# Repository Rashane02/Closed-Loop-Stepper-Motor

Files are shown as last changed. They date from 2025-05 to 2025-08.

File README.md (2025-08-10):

# 🚀 Closed-Loop Stepper Motor Control System  

A **high-performance closed-loop stepper motor system** powered by **Field-Oriented Control (FOC)** and **Space Vector Modulation (SVM)**, delivering **precise**, **smooth**, and **efficient motion control**.  

Real-time **encoder feedback** ensures **zero step loss**, even under heavy dynamic loads – making this system ideal for **robotics**, **CNC machines**, and **advanced automation** applications.  

---

## ✨ Features  

✅ **Closed-Loop Feedback** – Quadrature encoder eliminates step loss by constantly correcting position in real time.  
✅ **FOC (Field-Oriented Control)** – Decoupled torque & flux control for buttery-smooth motion.  
✅ **SVM (Space Vector Modulation)** – Generates efficient, optimized PWM waveforms.  
✅ **Dead-Time Insertion** – Prevents MOSFET shoot-through for safe, reliable switching.  
✅ **Multi-Mode Control**:  
   - 🎯 **Torque Mode** – Direct torque regulation via Q-axis current.  
   - ⚡ **Speed Mode** – Outer PI speed loop for consistent velocity.  
   - 📍 **Position Mode** – Expandable to precision positioning applications.  
✅ **Load Disturbance Compensation** – Maintains performance under sudden mechanical shocks.  

---

## 🛠 Hardware Setup  

- **Stepper Motor**: NEMA17 w/ integrated magnetic encoder  
- **Encoder**: Quadrature rotary encoder  
- **MCU**: TI **TMS320F28069M** (C2000 series – optimized for motor control)  
- **Driver**: Toshiba **TB67H400A** H-bridge driver  
- **Power Supply**: 24V SMPS  
- **Dev Board**: TI **LAUNCHXL-F28069M** + XDS110 Debugger  

---

## 🧠 Software Architecture  

- 🌀 **FOC Engine** – Implements **Clarke & Park transforms** for current regulation.  
- ⚙️ **Current Control Loop** – Inner PI loop for **Id/Iq** current control.  
- 🚀 **Speed Control Loop** – Outer PI loop regulates speed based on encoder feedback.  
- 🔺 **SVM** – Generates smooth PWM signals for precise voltage vector control.  
- ⏱ **Dead-Time Management** – Ensures MOSFET safety during commutation.  
- 🎯 **Encoder Interface (eQEP)** – Real-time speed & position tracking.  
- 📊 **Current Sensing & Calibration** – Phase current monitoring with ADC correction.  
- ⚡ **Interrupt-Driven Control** – High-speed ISR-based execution for ultra-low latency.  
- 🎛 **PWM Generation** – Configured for **10 kHz switching** using TI’s ePWM modules.  
- 🔧 **Utility Layer** – IQmath-based helpers for sign detection, clamping & timing.  

---

## 🎮 Control Modes  

### 🔴 Torque Mode  
Controls motor torque **directly** by regulating Q-axis current. Perfect for force-sensitive applications like **robot arms** or **actuators**.  

### 🟠 Speed Mode  
A **cascaded PI loop** sets torque (Iq) based on speed error – ensuring **steady, ripple-free velocity**.  

### 🟢 Position Mode *(Scalable)*  
An **outer position loop** feeds commands to the speed loop – enabling high-precision motion like **CNC**, **pick-and-place machines**, or **3D printers**.  

---

## 🔬 Prototype  

🖼 *Compact design built for performance testing*  

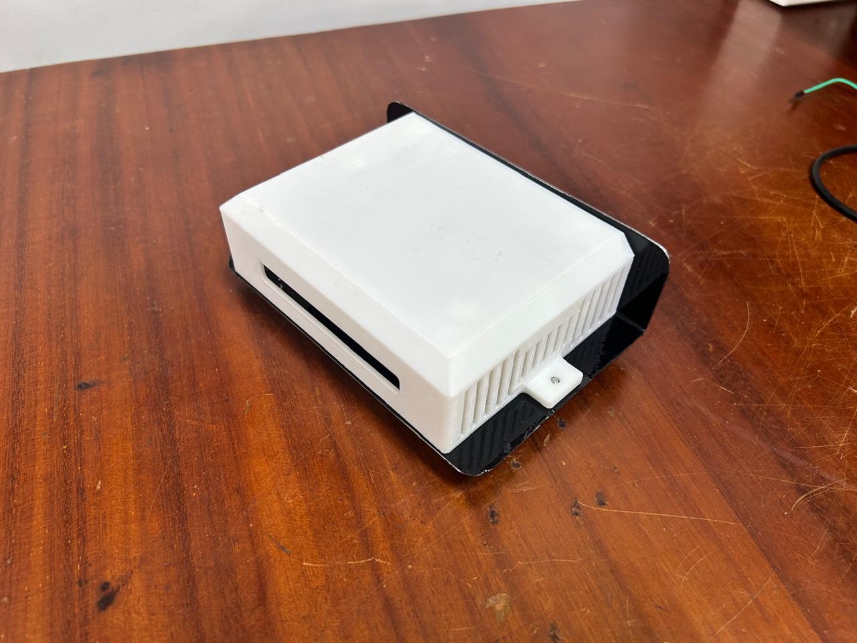
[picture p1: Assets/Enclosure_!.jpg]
  
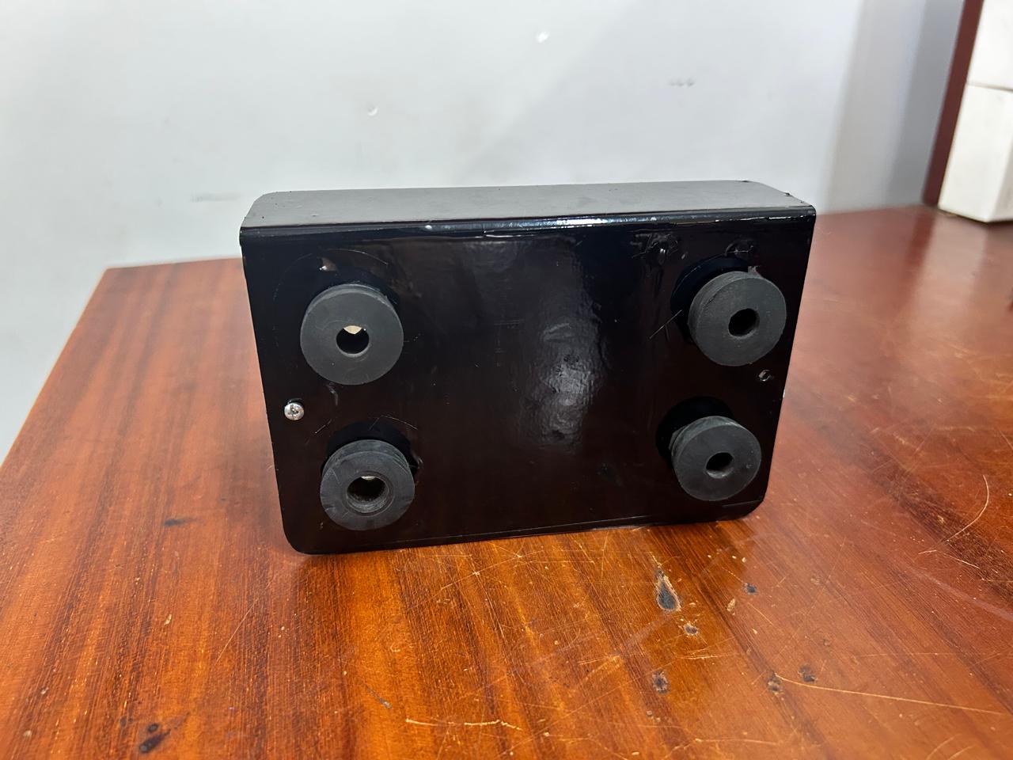
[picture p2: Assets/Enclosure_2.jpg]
  

---

## ⚡ PCB Design  

A **4-layer PCB** designed for **thermal efficiency**, **signal integrity**, and **high-current handling**.  

- ✅ Optimized power & ground planes for **low-noise FOC**.  
- ✅ Carefully routed encoder & current sense lines for **accurate feedback**.  
- ✅ Built-in dead-time safe switching logic.  

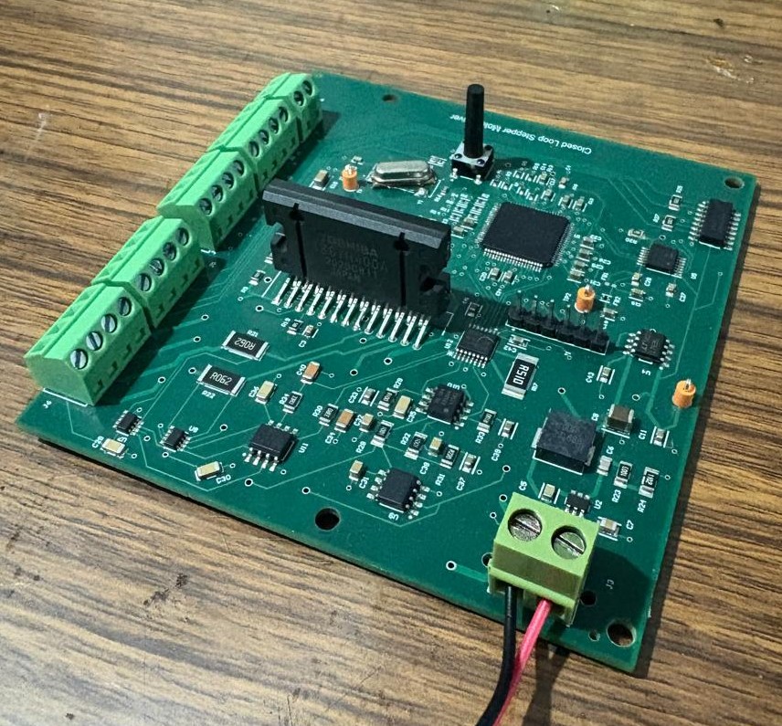
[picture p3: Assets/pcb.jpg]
  
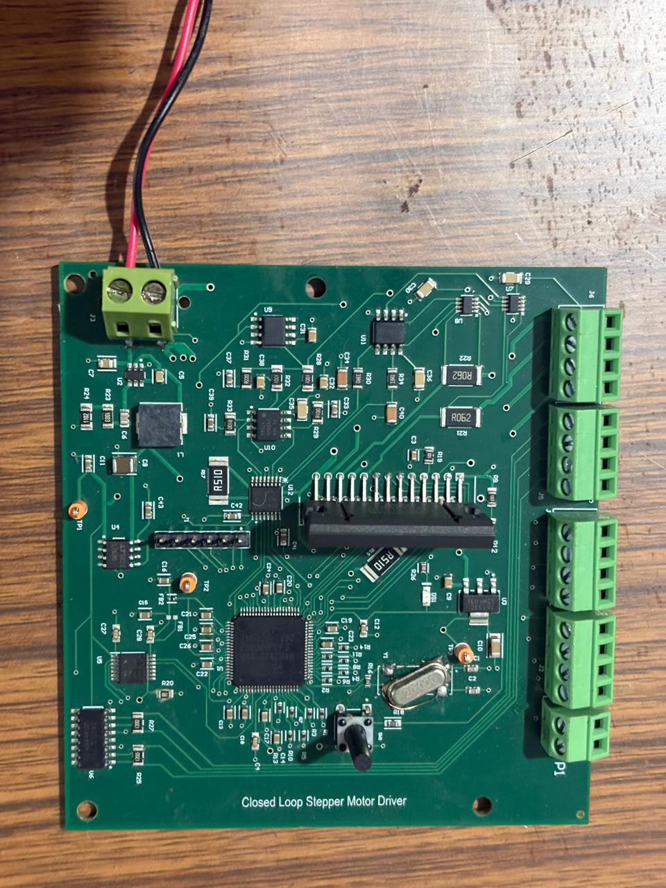
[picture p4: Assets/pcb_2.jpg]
  

---

## 📚 References  

📘 [TI – Field Oriented Control Overview](https://www.ti.com/video/6296584406001)  
📘 [TI – C2000 Motor Control User Guide](https://www.tij.co.jp/jp/lit/ug/spru556/spru556.pdf)  
📘 [TI – InstaSPIN FOC Documentation](https://www.ti.com/lit/pdf/sprui11)

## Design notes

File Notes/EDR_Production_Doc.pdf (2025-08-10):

## University of Moratuwa

## Faculty of Engineering

## Department of Electronic & Telecommunication Engineering

21st of May, 2025

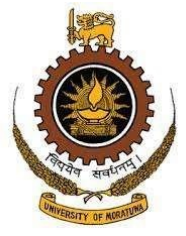
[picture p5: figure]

EN2160: Electronic Design Realization

## Production Documents for Closed Loop Stepper Motor Project

Group Members:

220169V | Fernando S.R.N.
220276V | Jayathissa M.P.N.V
220134K | Dissanayaka D.M.A.D.
220353F | Lakshan K.P.
220355M | Lakshan R.G.R.
220386H | Manujaya U.G.P.
220472T | Perera P.L.P.
220683P | Weerakoon W.M.B.H

# Contents

## 1 Introduction

This production report details the development of a closed-loop stepper motor control system designed for high-performance and cost-effective motion control applications. This project focuses on building a dedicated motor driver from scratch using a Texas Instruments C2000 series microcontroller. The system implements Field-Oriented Control (FOC) and real-time feedback

to achieve precise position and speed control, along with fault detection. The report outlines the complete production process, including hardware and software design, integration, testing and evaluation procedures, and cost estimation, providing a comprehensive plan for future scalability and manufacturing.

## 2 Block Diagram

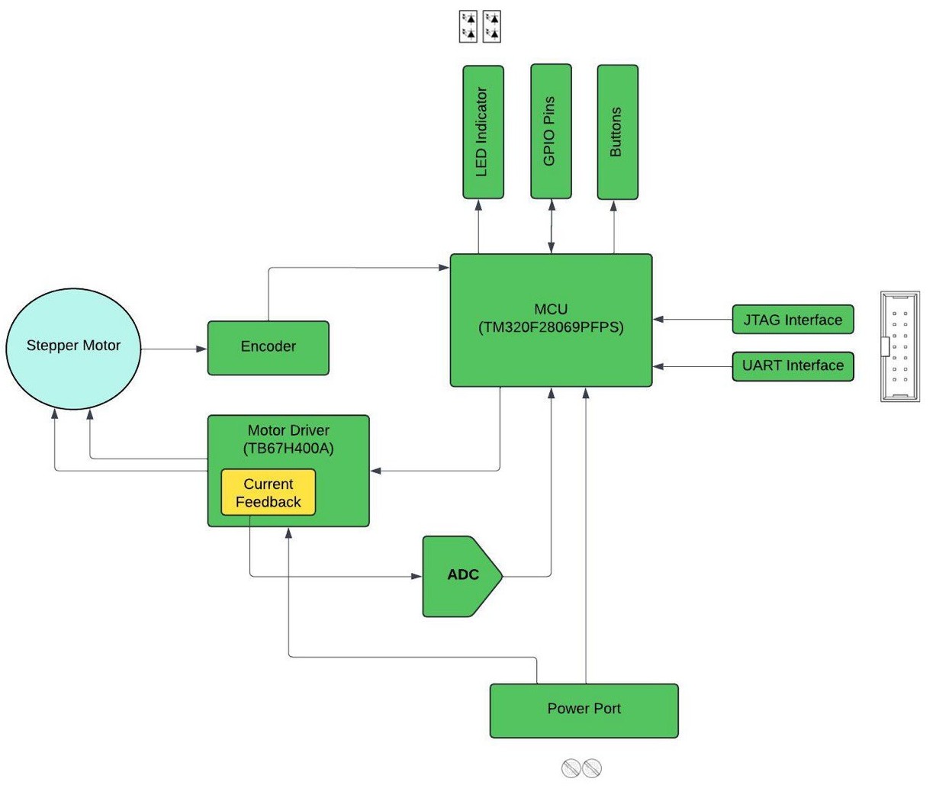
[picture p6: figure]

Figure 1: Block Diagram of the System

## 3 Hardware Design

### 3.1 Schematic

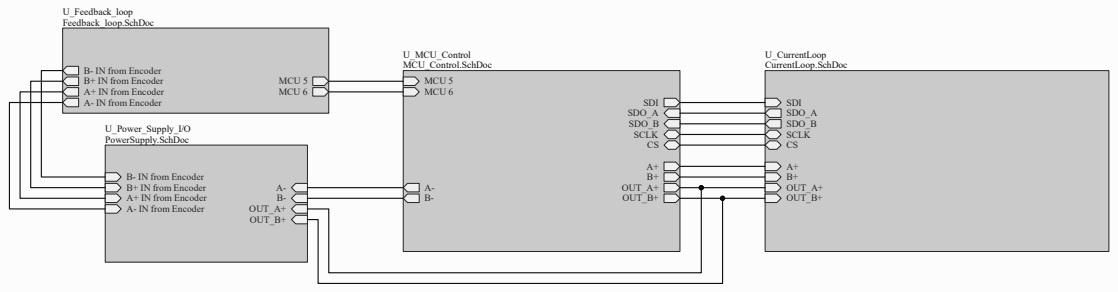
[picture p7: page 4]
Size; Number; Revision; Date:; Sheet of; File:; C:\Users\..\top_level.SchDoc; Drawn By:; 01 Version 5; Jayathissa M.P.N.V.; MCU 5 MCU 6; OUT_A+; OUT_B+; SDO_B; SDO_A; SDI; SCLK CS; U_MCU_Control MCU_Control.SchDoc; U_Feedback_loop Feedback_loop.SchDoc; SCLK; SDI SDO_A SDO_B; U_CurrentLoop CurrentLoop.SchDoc; U_Power_Supply_I/O PowerSupply.SchDoc

B- IN from Encoder
B+ IN from Encoder
A+ IN from Encoder
A- IN from Encoder

Title
Closed Loop Stepper- Top Level

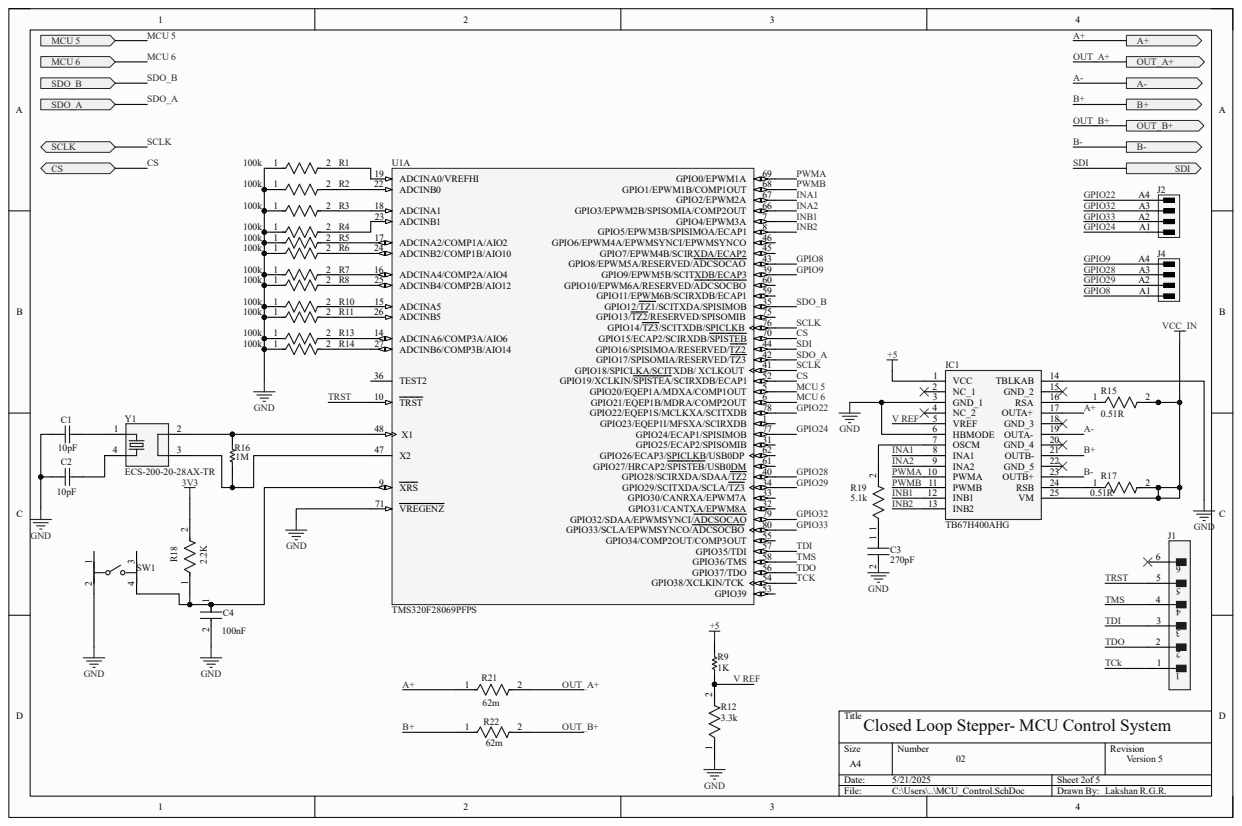
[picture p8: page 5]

Title
Closed Loop Stepper- MCU Control System

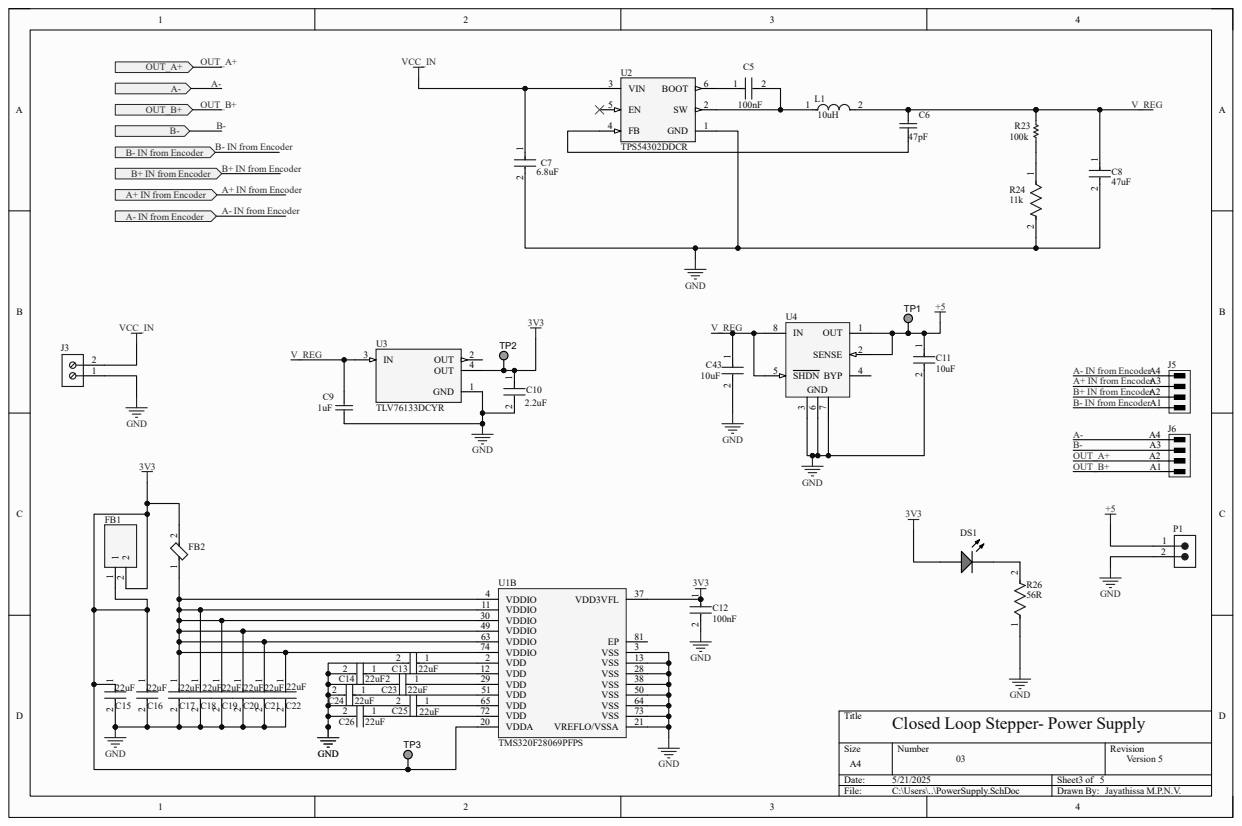
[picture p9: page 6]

Title
Closed Loop Stepper- Power Supply

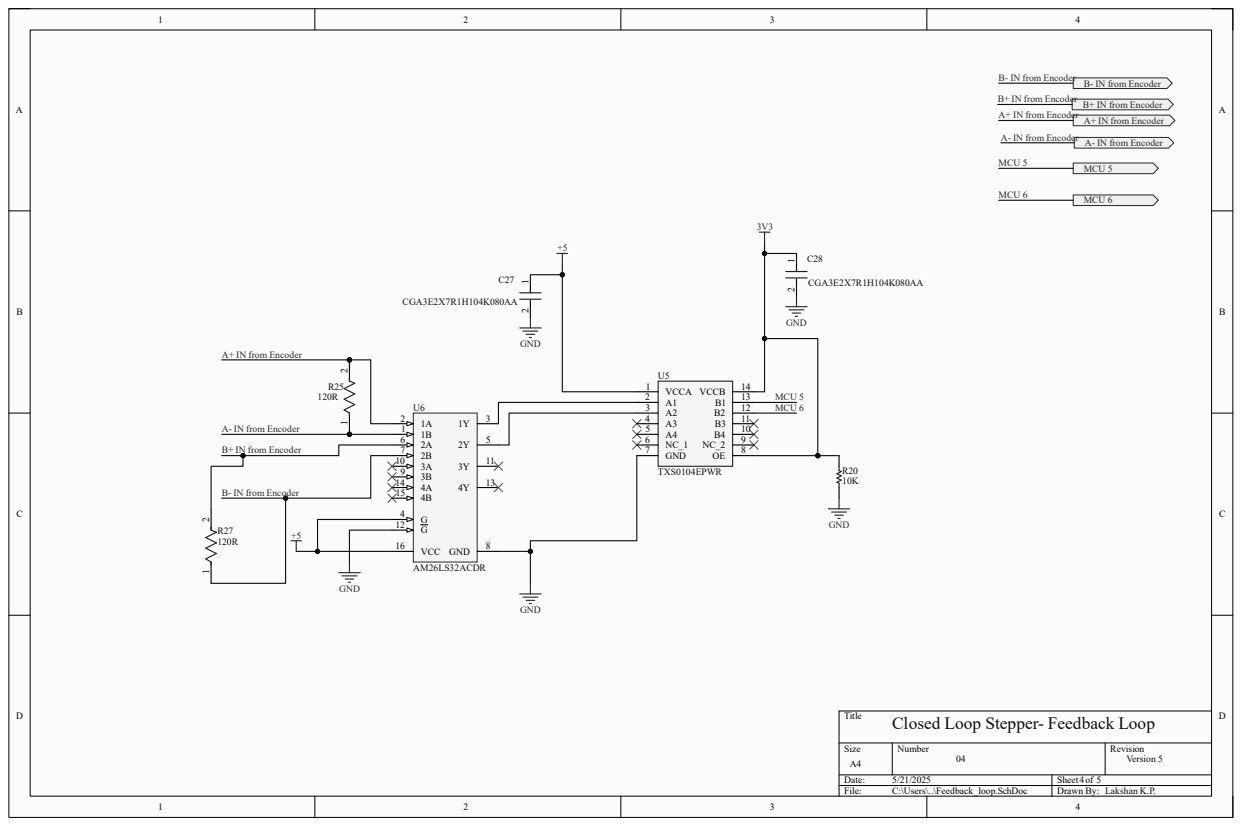
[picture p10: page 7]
Size; Number; Revision; Date:; Sheet of; File:; C:\Users\..\Feedback_loop.SchDoc; Drawn By:; 04 Version 5; GND; VCC 16; AM26LS32ACDR; CGA3E2X7R1H104K080AA; VCCA 1 A1 2 A2 3 A3 4 A4 5 NC_1 6 GND 7; VCCB; TXS0104EPWR; MCU 5 MCU 6; MCU 5; MCU 6; Lakshan K.P.

B- IN from Encoder

B+ IN from Encoder
A+ IN from Encoder

A- IN from Encoder

Title
Closed Loop Stepper- Feedback Loop

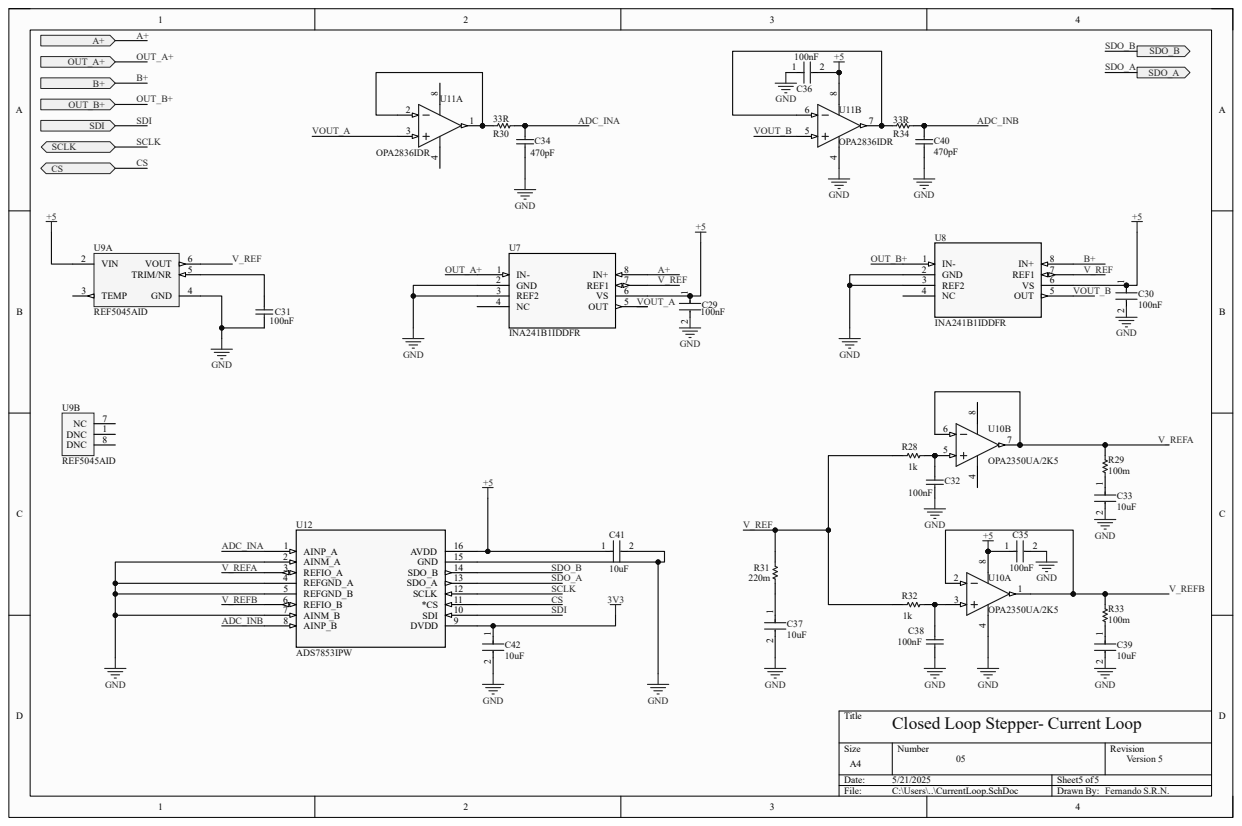
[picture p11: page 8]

GND
Closed Loop Stepper- Current Loop

### 3.2 Components

Designator | Description | Manufacturer / Part Number
C1, C2 | 10pF, ±5%, 50V, 0603, NP0 | Yageo / CC0603JRNPO9BN100
C3 | 270pF, 50V, C0G/NP0, 0603 | KEMET / C0603C271J5GACTU
C4, C12, C27, C28 | 100nF, 50V, X7R, 0603, Automotive | TDK / CGA3E2X7R1H104K080AA
C5 | 0.1uF, 50V, X7R, 0805 | KEMET / C0805C104M5RACTM
C6 | 470pF, 50V, NP0, 0805 | Murata / GQM2195C1H470JB01D
C7 | 6.8uF, 35V, X5R, 0805 | TDK / C2012X5R1V685K125AC
C8 | 47uF, 16V, X5R, 1210 | Murata / GRM32ER61C476KE15L
C9, C31, C32, C38 | 0.1uF, 50V, X7R, 0805 | Kyocera AVX / C0805C105K4PACTU
C10 | 2.2uF, 100V, X7S, 1206 | TDK / C3216X7S2A225K160AB
C11, C33, C37, C39, C41–C43 | 10uF, 6.3V, X5R, 0603 | Murata / GRM188R60J106ME47D
C13–C26 | 22uF, 10V, X5R, 0603 | Murata / GRM188R61A226ME15D
C29, C30, C35, C36 | 0.1uF, 100V, X7R, 1206 | KEMET / C1206C104K1RACTU
C34, C40 | 470pF, 500V, 1206 | Kyocera AVX / 12067A471JAT2A
DS1 | Green Chip LED, 2.2V | Broadcom Avago / HSMG-C170
FB2 | 60Ω, 100MHz, 0402F erriteBead | Murata / BLM15PD600SN1D
J1 | CONN HEADER VERT 6POS 2.54MM | Molex / 22-28-4060
J2, J4–J6 | Terminal Block, 3.50mm | Weidmuller / 1604490000
J3 | 2-pin Terminal Block | Wurth Electronics / 691709710302
L1 | Inductor 10uH, 4.5A | Vishay Dale / IHLP2525EZER100M01

Designator | Description | Manufacturer / Part Number
P1 | 2-pin Header | Wurth Electronics / 691321100002
R1–R14 | 100kΩ, 1/16W, 0402 | Yageo / RC0402JR-07100KL
R9 | 1kΩ, 1%, 0805 | Yageo / RC0805FR-071KL
R12 | 3.3kΩ, 1%, 0805 | Vishay / CRCW08053K30FKEA
R15, R17 | 0.51Ω, 1%, 2W, 2512 | Stackpole / CSRN2512FTR510
R16 | 1MΩ, 5%, 0603 | Panasonic / ERJ-3GEYJ105V
R18 | 2.2kΩ, 1%, 0603 | Vishay / CRCW06032K20FKEAHP
R19 | 5.1kΩ, 1%, 0805 | Vishay / CRCW08055K10FKEA
R20 | 10kΩ, 1%, 0805 | Yageo / RC0805FR-0710KL
R21, R22 | 0.062Ω, 1%, 1W, 2512 | Rohm / MCR100JZHFSR062
R23 | 100kΩ, 1%, 1206 | Bourns / CR1206-FX-1003ELF
R24 | 11kΩ, 1%, 1206 | Vishay / CRCW120611K0FKEA
R25, R27 | 120Ω, 1%, 1206 | Vishay / CRCW1206120RFKEA
R26 | 56Ω, 5%, 0603 | Vishay Dale / CRCW060356R0JNEA
R28, R32 | 1kΩ, 1%, 1206 | Yageo / RC1206FR-071KL
R29, R33 | 100mΩ, 1%, 1206 | Vishay Dale / WSL1206R1000FEA
R30, R34 | 33Ω, 1%, 1206 | Panasonic / ERJ-8ENF33R0V
R31 | 0.22Ω, 1%, 1206 | Panasonic / ERJ-8RQFR22V
SW1 | Tactile Switch SPST-NO, 0.05A 24V | TE Connectivity / 3-1825910-1
TP1–TP3 | Test Point, Orange, THD | Keystone / 5003
U1 | Piccolo Microcontroller, 80-pin HTQFP | TI / TMS320F28069PFPS
U2 | Buck Regulator 3A, TSOT-23-6 | TI / TPS54302DDCR

Designator | Description | Manufacturer / Part Number
U3 | 1A Linear Regulator, 16V, SOT-223 | TI / TLV76133DCYR
U4 | 500mA LDO Regulator, SOIC-8 | Analog Devices / LT1763CS8-5TRPBF
U6 | Line Receiver, 16-Pin SOIC | TI / AM26LS32ACDR
U9 | Precision Voltage Ref, 8-Pin SOIC | TI / REF5045AID
U10 | Rail-to-Rail Op Amp, SOIC-8 | TI / OPA2350UA/2K5
U11 | Dual Op Amp, SOIC-8 | TI / OPA2836IDR

Table 1: Full Bill of Materials (BOM)

Component Designator | Price (USD)
C1, C2 | 0.20
C3 | 0.10
C4, C12, C27, C28 | 0.38
C5 | 0.10
C6 | 0.10
C7 | 0.60
C8 | 1.23
C9, C31, C32, C38 | 0.14
C10 | 0.53
C11, C33, C37, C39, C41–C43 | 0.46
C13–C26 | 0.56
C29, C30, C35, C36 | 0.64
C34, C40 | 0.76
DS1 | 0.28
FB2 | 0.10
J1 | 0.12
J2, J4–J6 | 8.32
J3 | 2.68
L1 | 1.72
P1 | 0.40
R1–R14 | 0.07
R9 | 0.10
R12 | 0.03
R15, R17 | 0.74
R16 | 0.10
R18 | 0.02
R19 | 0.02
R20 | 0.10

Component Designator | Price (USD)
R21, R22 | 0.02
R23 | 0.01
R24 | 0.02
R25, R27 | 0.03
R26 | 0.03
R28, R32 | 0.20
R29, R33 | 0.46
R30, R34 | 0.32
R31 | 0.22
SW1 | 0.08
TP1–TP3 | 0.84
U1 | 18.05
U2 | 0.80
U3 | 0.41
U4 | 6.71
U6 | 0.55
U9 | 4.00
U10 | 4.54
U11 | 3.82
Total Component Cost | 58.58

Table 2: Component Prices and Total Cost

### 3.3 PCB Layer Stackup

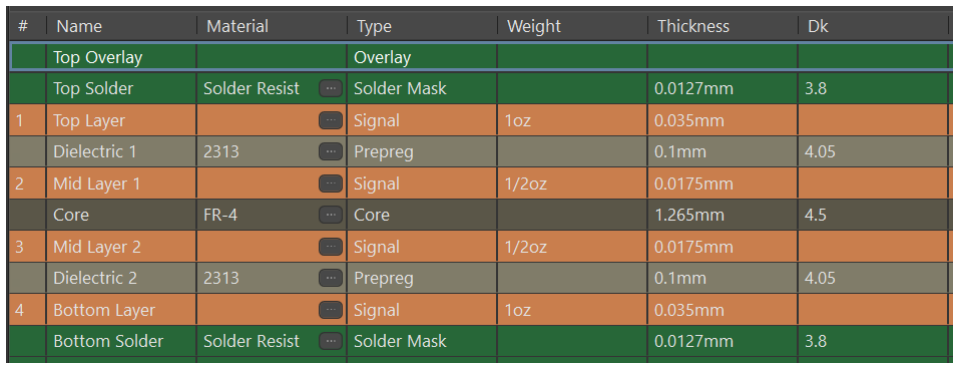
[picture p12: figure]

Figure 2: PCB Layer Stackup

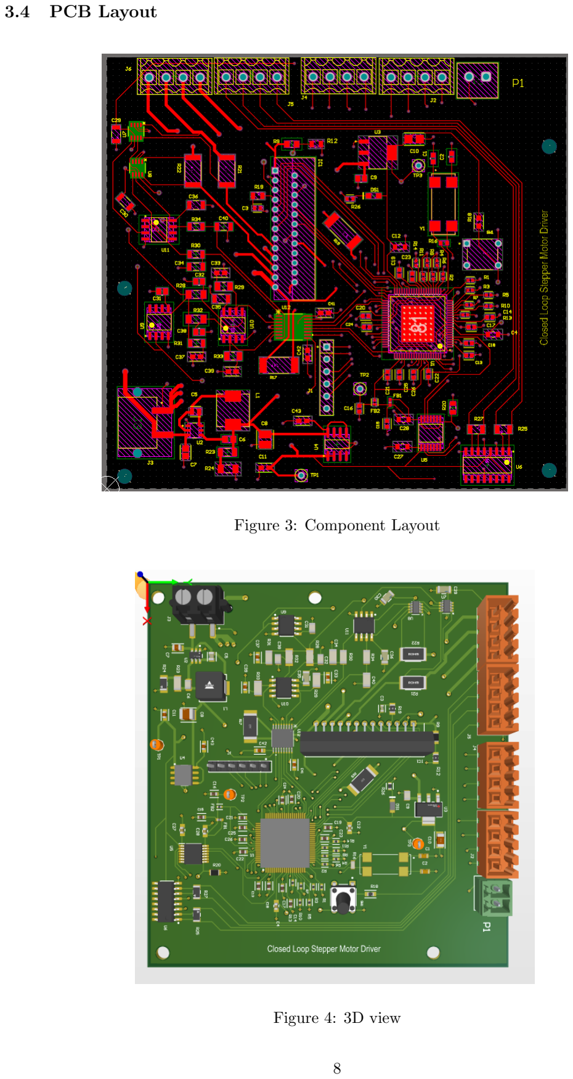
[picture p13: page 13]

### 3.4 PCB Layout

Figure 3: Component Layout

Figure 4: 3D view

PCB design documents can be accessed from this link: https://github.com/Rashane02/Closed-

Loop-Stepper-Motor (https://github.com/Rashane02/Closed-Loop-Stepper-Motor)

### 3.5 Enclosure Design

External View

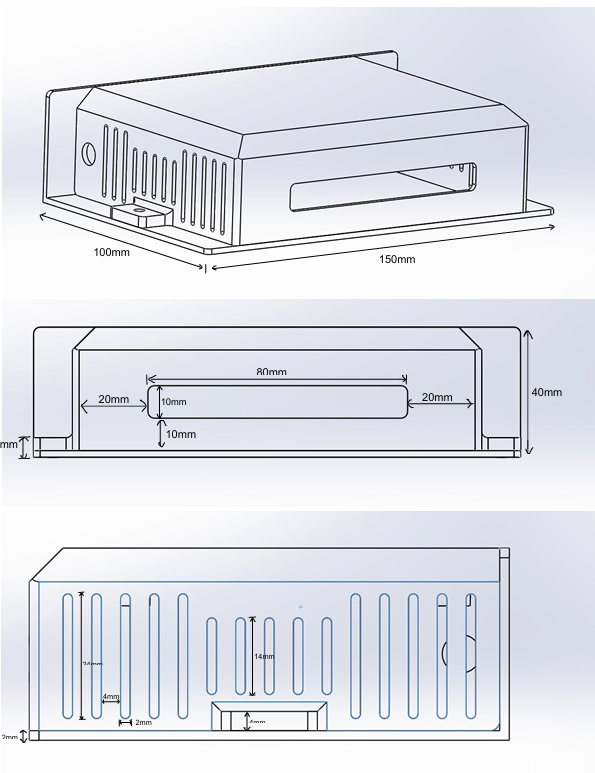
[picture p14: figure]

Figure 5: External Parameters

Internal View

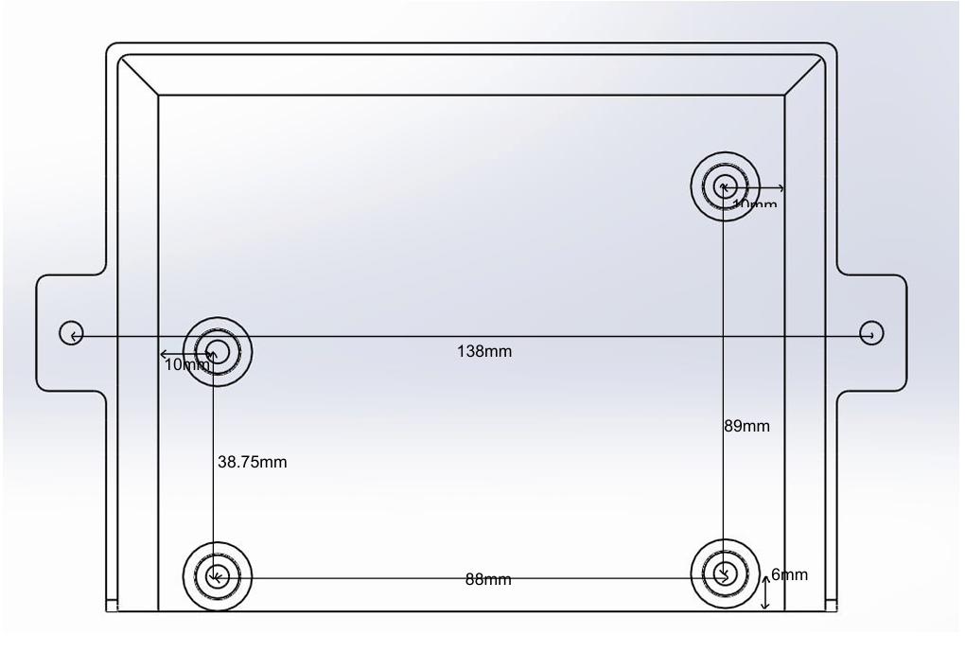
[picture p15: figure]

Figure 6: Internal Parameters

3D View

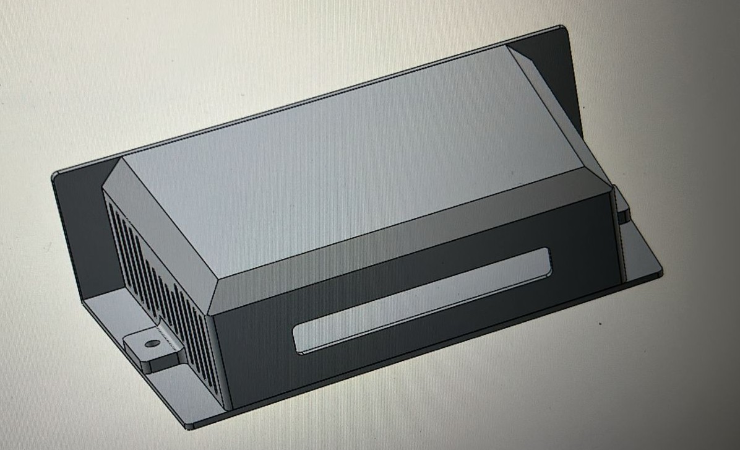
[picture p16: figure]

Figure 7: 3D View

Enclosure is manufactured as two parts. The bottom part is made out of metal while the top part is made out of thermoplastic polymer. PCB design documents can be accessed from this link: https://github.com/Rashane02/Closed-Loop-Stepper-Motor

## 4 Software Development

Software development tools used:

- CCS Studio by Texas Instruments
- MATLAB

Programming languages used: C/C++

Code used for programming can be accessed from the link below: https://github.com/Rashane02/Closed-Loop-Stepper-Motor

## 5 Estimated Cost Per Unit

Category | Cost (USD)
Component Cost (refer table 2) PCB Printing Cost Enclosure Cost Other Costs | 58.58 1.40 10.00 10.00
Total Estimated Cost per Unit | 79.98

Table 3: Estimated Cost per Unit (USD)

## 6 Component Datasheets

- TMS320F28069PFPS: https://www.ti.com/lit/gpn/TMS320F28069
- TBH67H400A: https://www.micro-semiconductor.nz/datasheet/de-TB67S149FTG-EL.pdf
- ADS7853: https://www.ti.com/lit/ds/symlink/ads7853.pdf
- INA241B: https://www.ti.com/lit/gpn/INA241B
- REF5045: https://www.ti.com/lit/gpn/ref50
- TLV76133DCYR: https://www.ti.com/lit/gpn/TLV761
- TPS54302DDCR: https://www.ti.com/lit/ds/symlink/tps54302.pdf
- AM26LS32ACDR: https://www.ti.com/lit/ds/symlink/am26ls32a.pdf
- TXS0104EPWR: https://www.ti.com/lit/ds/symlink/txs0104e.pdf

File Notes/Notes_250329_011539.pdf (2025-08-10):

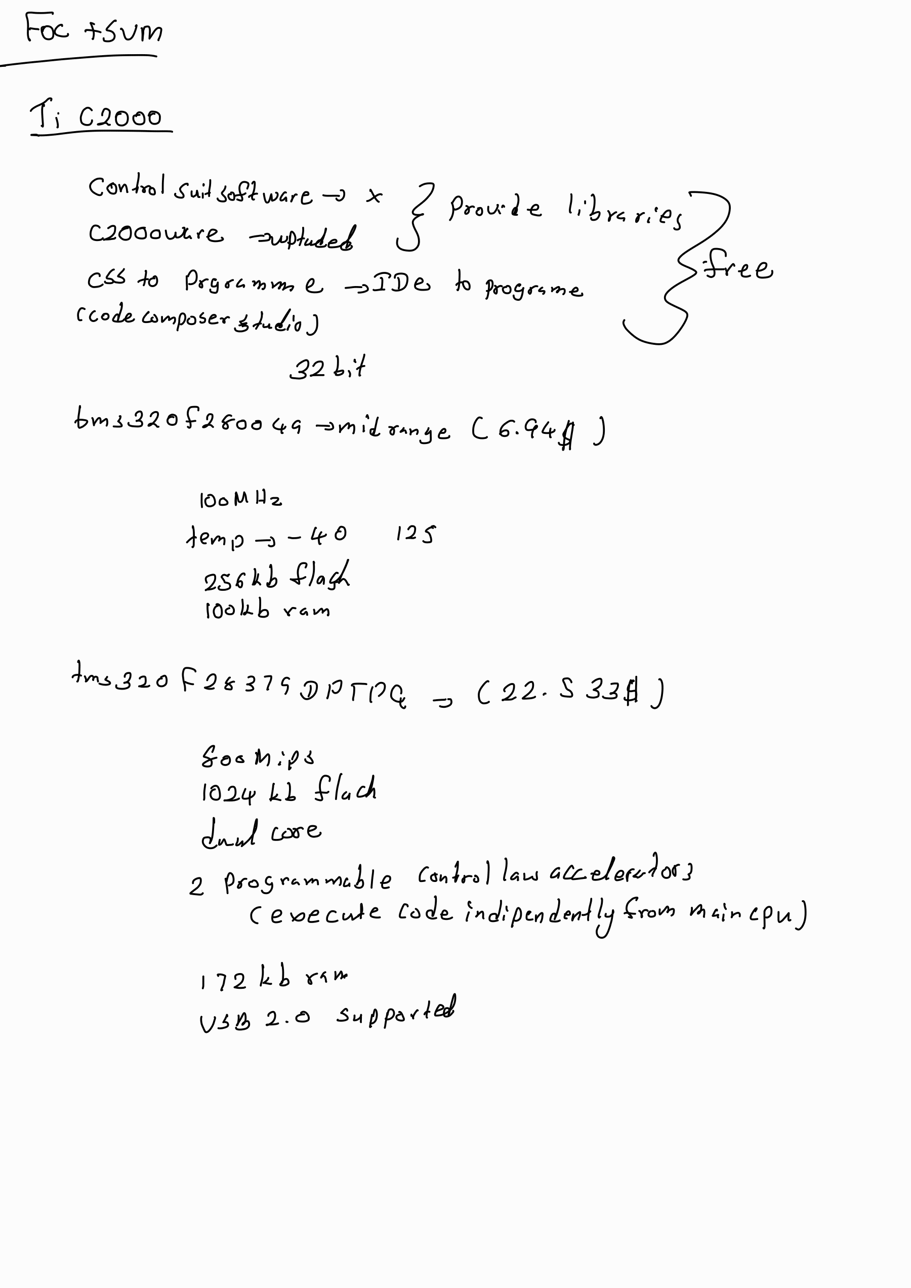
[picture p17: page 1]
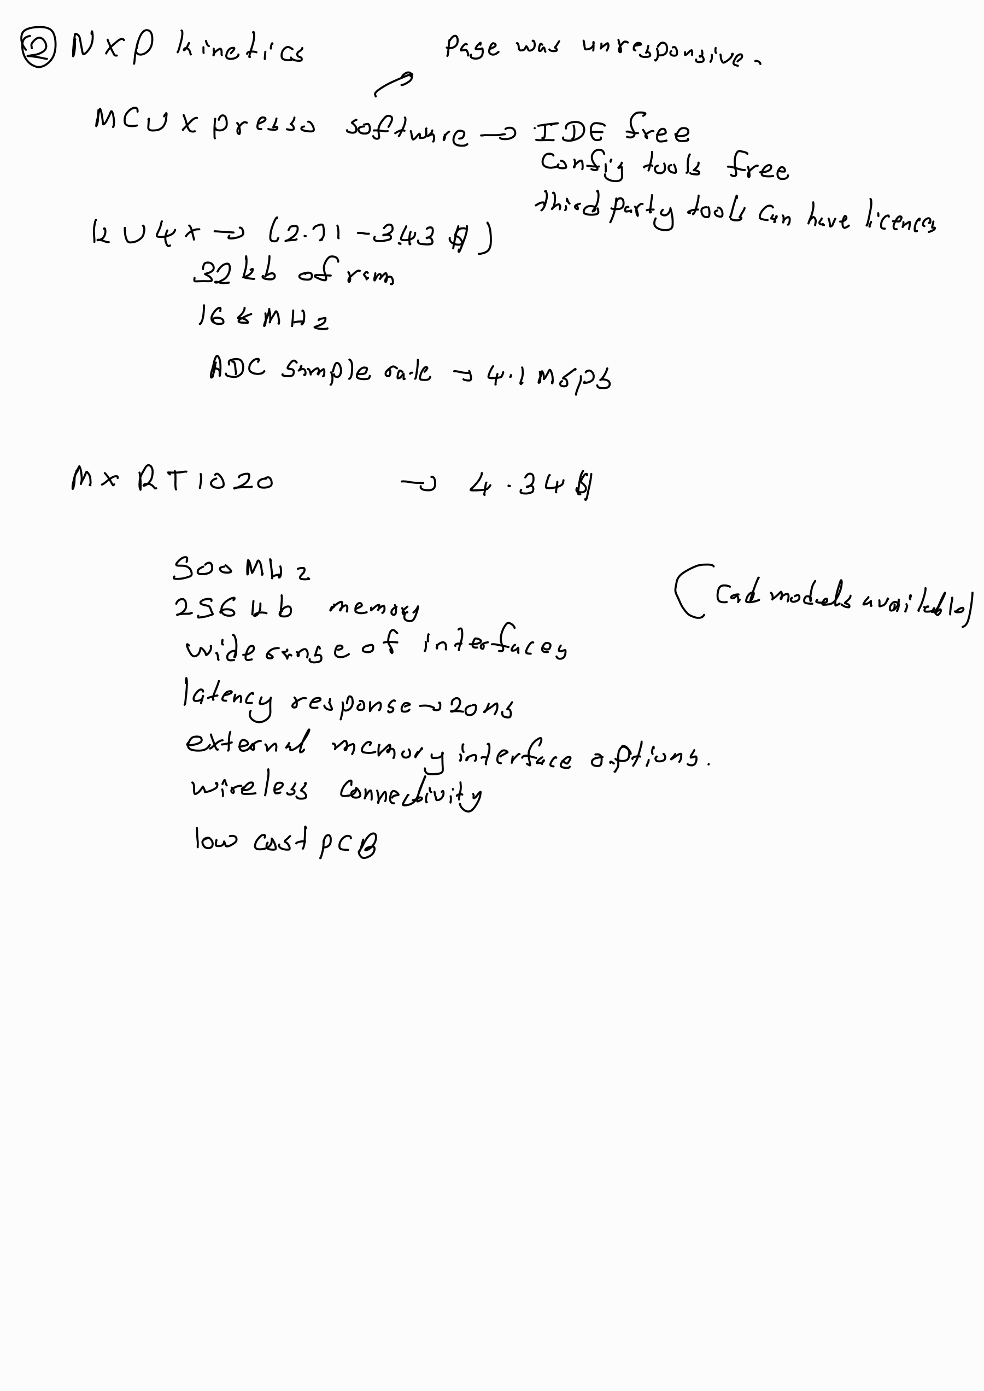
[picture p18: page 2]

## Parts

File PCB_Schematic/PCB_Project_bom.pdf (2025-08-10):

Line # | Name | Description | Designator | Revision ID | Revision State | Revision Status | Quantity | Manufacturer 1 | Manufacturer Part Number 1 | Manufacturer Lifecycle 1 | Supplier 1 | Supplier Part Number 1 | Supplier Unit Price 1 | Supplier Subtotal 1
| CC0603JRNPO9BN1 00 | Chip Capacitor, 10 pF, +/- 5%, 50 V, -55 to 125 degC, 0603 (1608 Metric), RoHS, Tape and Reel | C1, C2 | CMP-2100-03593-1 | Released | Up to date | | 2 Yageo | CC0603JRNPO9BN100 | Volume Production | Mouser | 603-C0603JRNPO9BN100 | | 0.1 | 0.2
| C0603C271J5GACT U | CAP CER 270PF 50V C0G/NP0 0603 | C3 | CMP-2006-03310-2 | New From Design | Up to date | | 1 KEMET | C0603C271J5GACTU | Volume Production | Digikey | 399-C0603C271J5GACTUCT-ND | | 0.1 | 0.1
| CGA3E2X7R1H104K 080AA | Cap Ceramic 100nF 50V X7R 10% Pad Automotive T/R SMD 0603 +125°C | C4, C12, C27, C28 | CMP-2000-07546-2 | New From Design | Up to date | | 4 TDK | CGA3E2X7R1H104K080AA | Volume Production | Newark | 05X9643 | 0.038 | | 0.38
| C0805C104M5RAC TU | CAP CER 0.1UF 50V X7R 0805 | C5 | CMP-1036-04423-3 | New From Design | Up to date | | 1 KEMET | C0805C104M5RACTM | Volume Production | Mouser | 80-C0805C104M5RACTM | | 0.1 | 0.1
| GQM2195C1H470JB 01D | | C6 | CMP-2007-03823-1 | Released | Up to date | | 1 Murata | GQM2195C1H470JB01D | Obsolete
| C2012X5R1V685K1 25AC | Multilayer Ceramic Capacitors 6.8μF ±10% 35V X5R SMD 0805 | C7 | CMP-08246-006695-1 | New From Design | Up to date | | 1 TDK | C2012X5R1V685K125AC | Not Recommended for New Design | Digikey | 445-14433-1-ND | | 0.6 | 0.6
| GRM32ER61C476KE 15L | CAP CER 47UF 16V X5R 1210 | C8 | CMP-2000-06362-2 | Released | Up to date | | 1 Murata | GRM32ER61C476KE15L | Not Recommended for New Design | Digikey | 490-6539-6-ND | 1.23 | | 1.23
| C0805C105K4PACT U | | C9, C31, C32, C38 | CMP-1036-04746-2 | Released | Up to date | | 4 Kyocera AVX | 0805YC105KAT2A | Volume Production | Newark | 96M1298 | 0.034 | 0.136
| C3216X7S2A225K1 60AB | Multilayer Ceramic Capacitors 2.2uF ±10% 100V X7S SMD 1206 | C10 | CMP-08246-004303-1 | New From Design | Up to date | | 1 TDK | C3216X7S2A225K160AB | Volume Production | Mouser | 810-C3216X7S2A225K | 0.53 | | 0.53
| GRM188R60J106ME 47D | Chip Multilayer Ceramic Capacitors for General Purpose, 0603, 10uF, X5R, 15%, 20%, 6.3V | C11, C33, C37, C39, C41, C42, C43 | CMP-2006-02792-2 | New From Design | Up to date | | 7 Murata | GRM188R60J106ME47D | Volume Production | Newark | 24R6334 | 0.065 | 0.455
| GRM188R61A226M E15D | Chip Multilayer Ceramic Capacitors for General Purpose, 0603, 22uF, X5R, 15%, 20%, 10V | C13, C14, C15, C16, C17, C18, C19, C20, C21, C22, C23, C24, C25, C26 | CMP-2000-06337-3 | New From Design | Up to date | | 14 Murata | GRM188R61A226ME15D | Volume Production | Digikey | 490-10476-1-ND | 0.04 | | 0.56
| C1206C104K1RACT U | CAP CER 0.1UF 100V X7R 1206 | C29, C30, C35, C36 | CMP-03020-000153-1 | New From Design | Up to date | | 4 KEMET | C1206C104K1RACTU | Volume Production | Newark | 85C2205 | 0.16 | | 0.64
| CAP 470pF 500V 1206(3216) | CAP 470pF 500V ±5% 1206 (3216 Metric) Thickness 1.3mm SMD | C34, C40 | CMP-1037-02174-1 | Released | Up to date | | 2 Kyocera AVX | 12067A471JAT2A | Volume Production | Digikey | 478-KGM31VCG2H471JUCT-ND | 0.38 | | 0.76
| HSMG-C170 | Chip LED, Green, 2.2 V, -40 to 85 degC, 2-Pin SMD, Pb-Free, Tape and Reel | DS1 | CMP-2000-05062-1 | Released | Up to date | | 1 Broadcom Avago | HSMG-C170 | Volume Production | Mouser | 630-HSMG-C170 | 0.28 | | 0.28
| BKP1005HS221-T | Ferrite Bead | FB1 | | Not managed | | | 1
| BLM15PD600SN1D | Chip Ferrite Bead, 0402, 60Ω @ 100MHz, 0.06Ω, 25%, 1.7A | FB2 | CMP-0686-00129-3 | Released | Up to date | | 1 Murata | BLM15PD600SN1D | Volume Production | Digikey | 490-5201-1-ND | | 0.1 | 0.1
| TB67H400AHG | Integrated Circuit | IC1 | | Not managed | | | 1
| 22-28-4060 | CONN HEADER VERT 6POS 2.54MM | J1 | CMP-04776-000763-1 | New From Design | Up to date | | 1 Molex | 22-28-4060 | Volume Production | Avnet | 0022284060 | 0.11966 | 0.11966
| 1604490000 | OMNIMATE Signal -series BL/SL 3.50 | J2, J4, J5, J6 | CMP-1559-00905-1 | Released | Up to date | | 4 Weidmuller | 1604490000 | Volume Production | Avnet | 56J9552 | 2.08 | | 8.32
| 691709710302 | | J3 | CMP-1502-03335-2 | Released | Up to date | | 1 Wurth Electronics Midcom | 691709710302 | Volume Production | Mouser | 710-691709710302 | 2.68 | | 2.68
| IHLP2525EZER100 M01 | Commercial Inductors, High Saturation Series 10uH 4.5A 71.3mΩ 20% | L1 | CMP-02424-000296-1 | New From Design | Up to date | | 1 Vishay Dale | IHLP2525EZER100M01 | Volume Production | Mouser | 70-IHLP2525EZER100M0 | 1.72 | | 1.72
| 691321100002 | | P1 | CMP-1502-01783-2 | Released | Up to date | | 1 Wurth Electronics | 691321100002 | Volume Production | Digikey | 732-2763-ND | | 0.4 | 0.4
| RC0402JR-07100KL | RES 100K OHM 5% 1/16W 0402 | R1, R2, R3, R4, R5, R6, R7, R8, R10, R11, R13, R14 | CMP-2002-07913-2 | Released | Up to date | | 12 Yageo | RC0402JR-07100KL | Volume Production | Digikey | 311-100KJRDKR-ND | 0.006 | 0.072
| RC0805FR-071KL | Chip Resistor, 1 KOhm, +/- 1%, 125 mW, -55 to 155 degC, 0805 (2012 Metric), RoHS, Tape and Reel | R9 | CMP-2100-03671-1 | Released | Up to date | | 1 Yageo | RC0805FR-071KL | Volume Production | Mouser | 603-RC0805FR-071KL | | 0.1 | 0.1
| CRCW08053K30FK EA | RES Thick Film, 3.3kΩ, 1%, 0.125W, 100ppm/ °C, 0805 | R12 | CMP-2001-03876-2 | New From Design | Up to date | | 1 Vishay | CRCW08053K30FKEA | Volume Production | Newark | 53K0097 | 0.026 | 0.026
| CSRN2512FTR510 | Res Thick Film 2512 0.51Ω 1% 2W ±200ppm/°C Molded SMD Plastic T/R | R15, R17 | CMP-26527-003119-1 | New From Design | Up to date | | 2 Stackpole Electronics | CSRN2512FTR510 | Volume Production | Digikey | 738-CSRN2512FTR510CT-ND | 0.37 | | 0.74
| ERJ-3GEYJ105V | | R16 | CMP-2000-00706-1 | Released | Up to date | | 1 Panasonic | ERJ-3GEYJ105V | Volume Production | Digikey | P1.0MGCT-ND | | 0.1 | 0.1
| CRCW06032K20FK EAHP | RES Thick Film, 2.2kΩ, 1%, 0.33W, 100ppm/°C, 0603 | R18 | CMP-02407-010809-1 | New From Design | Up to date | | 1 Vishay | CRCW06032K20FKEAHP | Volume Production | Newark | 65AC3387 | 0.022 | 0.022
| CRCW08055K10FK EA | RES Thick Film, 5.1kΩ, 1%, 0.125W, 100ppm/ °C, 0805 | R19 | CMP-2001-04024-2 | New From Design | Up to date | | 1 Vishay | CRCW08055K10FKEA | Volume Production | Avnet | 53K0298 | 0.015 | 0.015
| RC0805FR-0710KL | Chip Resistor, 10 KOhm, +/- 1%, 0.125 W, -55 to 155 degC, 0805 (2012 Metric), RoHS, Tape and Reel | R20 | CMP-1659-00013-4 | Released | Up to date | | 1 Yageo | RC0805FR-0710KL | Volume Production | Newark | 05M4535 | | 0.1 | 0.1
| MCR100JZHFSR062 | Thick Film Chip Resistor, 2512, 0.062Ω, 1%, 1W, 200V | R21, R22 | CMP-08839-019952-1 | New From Design | Up to date | | 2 Rohm | MCR100JZHFSR062 | Volume Production
| CRCW1206100KFK EA | | R23 | CMP-1014-00736-2 | Released | Up to date | | 1 Bourns | CR1206-FX-1003ELF | Volume Production | Newark | 32K3578 | 0.009 | 0.009
| CRCW120611K0FK EA | RES Thick Film, 11kΩ, 1%, 0.25W, 100ppm/°C, 1206 | R24 | CMP-2003-04829-2 | New From Design | Up to date | | 1 Vishay | CRCW120611K0FKEA | Volume Production | Avnet | 53K1930 | 0.019 | 0.019
| CRCW1206120RFK EA | RES Thick Film, 120Ω, 1%, 0.25W, 100ppm/°C, 1206 | R25, R27 | CMP-2003-04838-2 | New From Design | Up to date | | 2 Vishay | CRCW1206120RFKEA | Volume Production | Newark | 27W4870 | 0.013 | 0.026
| CRCW060356R0JN EA | RES Thick Film, 56 Ω, 5%, 0.1W, 200ppm/°C, 0603 | R26 | CMP-2000-03472-2 | New From Design | Up to date | | 1 Vishay Dale | CRCW060356R0JNEA | Volume Production | Newark | 59M6825 | 0.003 | 0.003
| RC1206FR-071KL | Chip Resistor, 1 KOhm, +/- 1%, 0.25 W, -55 to 155 degC, 1206 (3216 Metric), RoHS, Tape and Reel | R28, R32 | CMP-2100-03678-1 | Released | Up to date | | 2 Yageo | RC1206FR-071KL | Volume Production | Mouser | 603-RC1206FR-071KL | | 0.1 | 0.2
| WSL1206R1000FEA | | R29, R33 | CMP-2003-04368-1 | Released | Up to date | | 2 Vishay Dale | WSL1206R1000FEA | Volume Production | Newark | 57J0997 | 0.23 | | 0.46
| ERJ8ENF33R0V | | R30, R34 | CMP-2003-00837-1 | Released | Up to date | | 2 Panasonic | ERJ-8ENF33R0V | Not Recommended for New Design | Digikey | P33.0FCT-ND | 0.16 | | 0.32
| ERJ-8RQFR22V | | R31 | CMP-2003-00694-1 | Released | Up to date | | 1 Panasonic | ERJ-8RQFR22V | Volume Production | Mouser | 667-ERJ-8RQFR22V | 0.22 | | 0.22
| 3-1825910-1 | SWITCH TACTILE SPST-NO 0.05A 24V | SW1 | CMP-03407-000001-1 | New From Design | Up to date | | 1 TE Connectivity | 3-1825910-1 | Volume Production | Avnet | 3-1825910-1 | 0.08231 | 0.08231
| 5003 | Test Point, Orange, Height 4.6 mm, Tail Length 3 mm, 1-Pin THD, RoHS | TP1, TP2, TP3 | | Unknown server | | | 3 Keystone Electronics | 5003 | Volume Production | Mouser | 534-5003 | 0.28 | | 0.84
| TMS320F28069PFP S | Piccolo Microcontroller, High-Efficiency 32-Bit CPU, 100 KB, 90 MHz, FPU, VCU, 17 Ch PWM, 40 GPIO, 3.3 V, -40 to 125 degC, 80-Pin HTQFP (PFP), Green (RoHS & no Sb/Br) | U1 | CMP-0546-00011-3 | Released | Up to date | | 1 Texas Instruments | TMS320F28069PFPS | Volume Production | Mouser | 595-TMS320F28069PFPS | 18.05 | 18.05
| TPS54302DDCR | IC REG BUCK ADJ 3A TSOT23-6 | U2 | CMP-04918-000032-1 | New From Design | Up to date | | 1 Texas Instruments | TPS54302DDCR | Volume Production | Arrow Electronics | TPS54302DDCR | 0.8014 | 0.8014
| TLV76133DCYR | TLV76133DCYR 1A 16V high-PSRR linear voltage regulator 4-SOT-223 -40 to 125 | U3 | CMP-00370-135533165-1 | New From Design | Up to date | | 1 Texas Instruments | TLV76133DCYR | Unknown | Mouser | 595-TLV76133DCYR | 0.41 | | 0.41
| LT1763CS8-5#TRPBF | 500 mA, Low Noise, LDO Micropower Regulator, 1.8 to 20 V Vin, 5 V Vout, 8-pin SOIC (S8-8), -40 to 125 degC, Pb-Free, Tape and Reel | U4 | CMP-0476-01689-1 | Released | Up to date | | 1 Analog Devices / Linear Technology | LT1763CS8-5#TRPBF | Volume Production | Mouser | 584-LT1763CS8-5TRPBF | 6.71 | | 6.71
| TXS0104EPWR | Integrated Circuit | U5 | | Not managed | | | 1
| AM26LS32ACDR | Quadruple Differential Line Receiver, 0 TX / 4 RX, 0 to 70 degC, 16-Pin SOIC (D), Green (RoHS & no Sb/Br) | U6 | CMP-0310-00258-2 | Released | Up to date | | 1 Texas Instruments | AM26LS32ACDR | Volume Production | Mouser | 595-AM26LS32ACDR | 0.55 | | 0.55
| INA241B1IDDFR | -5-V to 110-V, bidirectional, high-precision current sense amplifier with enhanced PWM rejection 8-SOT-23-THIN -40 to... | U7, U8 | | Not managed | | | 2
| REF5045AID | Voltage Reference, Low Noise, Very Low Drift, Precision -40 to 125 degC, 8-pin SOIC (D), Green (RoHS & no Sb/Br) | U9 | CMP-0367-00016-2 | Released | Up to date | | 1 Texas Instruments | REF5045AID | Volume Production | Mouser | 595-REF5045AID | | 4 | 4
| OPA2350UA/2K5 | High-Speed, Single-Supply, Rail-to-Rail Operational Amplifier MicroAmplifier(TM) Series, 2.7 to 5.5 V, -40 to 85 degC, 8-pin SOIC (D8), Green (RoHS & no Sb/Br) | U10 | CMP-0272-00732-3 | Released | Up to date | | 1 Texas Instruments | OPA2350UA/2K5 | Volume Production | Mouser | 595-OPA2350UA/2K5 | 4.54 | | 4.54
| OPA2836IDR | Dual, Very Low Power, Rail to Rail Out, Negative Rail In, VFB Operational Amplifier, 2.5 to 5.5 V, -40 to 85 degC, 8-pin SOIC (D8), Green (RoHS & no Sb/Br) | U11 | CMP-0018-00293-2 | Released | Up to date | | 1 Texas Instruments | OPA2836IDR | Volume Production | Digikey | 296-OPA2836IDRCT-ND | 3.82 | | 3.82
| ADS7853IPW | ADC, Proprietary Method, 14-Bit, 1 Func, 2 Channel, Serial Access, PDSO16 | U12 | | Not managed | | | 1
| ECS-200-20-28AX-TR | SMD Quartz Crystal | Y1 | | Not managed | | | 1

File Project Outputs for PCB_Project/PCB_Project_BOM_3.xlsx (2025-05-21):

Line # | Comment | Description | Designator | Revision ID | Revision State | Revision Status | Quantity | Manufacturer 1 | Manufacturer Part Number 1 | Manufacturer Lifecycle 1 | Supplier 1 | Supplier Part Number 1 | Supplier Unit Price 1 | Supplier Subtotal 1
 | CC0603JRNPO9BN100 | Chip Capacitor, 10 pF, +/- 5%, 50 V, -55 to 125 degC, 0603 (1608 Metric), RoHS, Tape and Reel | C1 | CMP-2100-03593-1 | Released | Up to date | 1 | Yageo | CC0603JRNPO9BN100 | Volume Production | Future Electronics | 1113642 | 0.0034 | 13.6
 | CC0603JRNPO9BN100 | Chip Capacitor, 10 pF, +/- 5%, 50 V, -55 to 125 degC, 0603 (1608 Metric), RoHS, Tape and Reel | C2 | CMP-2100-03593-1 | Released | Up to date | 1 | Yageo | CC0603JRNPO9BN100 | Volume Production | Future Electronics | 1113642 | 0.0034 | 13.6
 | C0603C271J5GACTU | CAP CER 270PF 50V C0G/NP0 0603 | C3 | CMP-2006-03310-2 | New From Design | Up to date | 1 | KEMET | C0603C271J5GACTU | Volume Production | Newark | 02E8737 | 0.009 | 288
 | CGA3E2X7R1H104K080AA | Cap Ceramic 100nF 50V X7R 10% Pad SMD 0603 +125°C Automotive T/R | C4 | CMP-2000-07546-2 | New From Design | Up to date | 1 | TDK | CGA3E2X7R1H104K080AA | Volume Production | Avnet | 04X3156 | 0.026 | 0.026
 | C0805C104M5RACTU | CAP CER 0.1UF 50V X7R 0805 | C5 | CMP-1036-04423-3 | New From Design | Up to date | 1 | KEMET | C0805C104M5RACTU | Volume Production
 | GQM2195C1H470JB01D |  | C6 | CMP-2007-03823-1 | Released | Up to date | 1 | Murata | GQM2195C1H470JB01D | Obsolete
 | C2012X5R1V685K125AC | Multilayer Ceramic Capacitors 6.8μF ±10% 35V X5R SMD 0805 | C7 | CMP-08246-006695-1 | New From Design | Up to date | 1 | TDK | C2012X5R1V685K125AC | Not Recommended for New Design | Newark | 29X4821
 | GRM32ER61C476KE15L | CAP CER 47UF 16V X5R 1210 | C8 | CMP-2000-06362-2 | Released | Up to date | 1 | Murata | GRM32ER61C476KE15L | Not Recommended for New Design | Newark | 14T3405 | 0.856 | 0.856
 | C0805C105K4PACTU |  | C9 | CMP-1036-04746-2 | Released | Up to date | 1 | TDK | C2012X5R1C105K/0.85 | Unknown
 | C3216X7S2A225K160AB | Multilayer Ceramic Capacitors 2.2uF ±10% 100V X7S SMD 1206 | C10 | CMP-08246-004303-1 | New From Design | Up to date | 1 | TDK | C3216X7S2A225K160AB | Volume Production | Farnell | 2112717 | 0.39891 | 1.99
 | GRM188R60J106ME47D | Chip Multilayer Ceramic Capacitors for General Purpose, 0603, 10uF, X5R, 15%, 20%, 6.3V | C11 | CMP-2006-02792-2 | New From Design | Up to date | 1 | Murata | GRM188R60J106ME47D | Volume Production | Newark | 03AC2652 | 0.019 | 76
 | CGA3E2X7R1H104K080AA | Cap Ceramic 100nF 50V X7R 10% Pad SMD 0603 +125°C Automotive T/R | C12 | CMP-2000-07546-2 | New From Design | Up to date | 1 | TDK | CGA3E2X7R1H104K080AA | Volume Production | Avnet | 04X3156 | 0.026 | 0.026
 | GRM188R61A226ME15D | Chip Multilayer Ceramic Capacitors for General Purpose, 0603, 22uF, X5R, 15%, 20%, 10V | C13 | CMP-2000-06337-3 | New From Design | Up to date | 1 | Murata | GRM188R61A226ME15D | Volume Production | Newark | 03AC2659 | 0.025 | 100
 | GRM188R61A226ME15D | Chip Multilayer Ceramic Capacitors for General Purpose, 0603, 22uF, X5R, 15%, 20%, 10V | C14 | CMP-2000-06337-3 | New From Design | Up to date | 1 | Murata | GRM188R61A226ME15D | Volume Production | Newark | 03AC2659 | 0.025 | 100
 | GRM188R61A226ME15D | Chip Multilayer Ceramic Capacitors for General Purpose, 0603, 22uF, X5R, 15%, 20%, 10V | C15 | CMP-2000-06337-3 | New From Design | Up to date | 1 | Murata | GRM188R61A226ME15D | Volume Production | Newark | 03AC2659 | 0.025 | 100
 | GRM188R61A226ME15D | Chip Multilayer Ceramic Capacitors for General Purpose, 0603, 22uF, X5R, 15%, 20%, 10V | C16 | CMP-2000-06337-3 | New From Design | Up to date | 1 | Murata | GRM188R61A226ME15D | Volume Production | Newark | 03AC2659 | 0.025 | 100
 | GRM188R61A226ME15D | Chip Multilayer Ceramic Capacitors for General Purpose, 0603, 22uF, X5R, 15%, 20%, 10V | C17 | CMP-2000-06337-3 | New From Design | Up to date | 1 | Murata | GRM188R61A226ME15D | Volume Production | Newark | 03AC2659 | 0.025 | 100
 | GRM188R61A226ME15D | Chip Multilayer Ceramic Capacitors for General Purpose, 0603, 22uF, X5R, 15%, 20%, 10V | C18 | CMP-2000-06337-3 | New From Design | Up to date | 1 | Murata | GRM188R61A226ME15D | Volume Production | Newark | 03AC2659 | 0.025 | 100
 | GRM188R61A226ME15D | Chip Multilayer Ceramic Capacitors for General Purpose, 0603, 22uF, X5R, 15%, 20%, 10V | C19 | CMP-2000-06337-3 | New From Design | Up to date | 1 | Murata | GRM188R61A226ME15D | Volume Production | Newark | 03AC2659 | 0.025 | 100
 | GRM188R61A226ME15D | Chip Multilayer Ceramic Capacitors for General Purpose, 0603, 22uF, X5R, 15%, 20%, 10V | C20 | CMP-2000-06337-3 | New From Design | Up to date | 1 | Murata | GRM188R61A226ME15D | Volume Production | Newark | 03AC2659 | 0.025 | 100
 | GRM188R61A226ME15D | Chip Multilayer Ceramic Capacitors for General Purpose, 0603, 22uF, X5R, 15%, 20%, 10V | C21 | CMP-2000-06337-3 | New From Design | Up to date | 1 | Murata | GRM188R61A226ME15D | Volume Production | Newark | 03AC2659 | 0.025 | 100
 | GRM188R61A226ME15D | Chip Multilayer Ceramic Capacitors for General Purpose, 0603, 22uF, X5R, 15%, 20%, 10V | C22 | CMP-2000-06337-3 | New From Design | Up to date | 1 | Murata | GRM188R61A226ME15D | Volume Production | Newark | 03AC2659 | 0.025 | 100
 | GRM188R61A226ME15D | Chip Multilayer Ceramic Capacitors for General Purpose, 0603, 22uF, X5R, 15%, 20%, 10V | C23 | CMP-2000-06337-3 | New From Design | Up to date | 1 | Murata | GRM188R61A226ME15D | Volume Production | Newark | 03AC2659 | 0.025 | 100
 | GRM188R61A226ME15D | Chip Multilayer Ceramic Capacitors for General Purpose, 0603, 22uF, X5R, 15%, 20%, 10V | C24 | CMP-2000-06337-3 | New From Design | Up to date | 1 | Murata | GRM188R61A226ME15D | Volume Production | Newark | 03AC2659 | 0.025 | 100
 | GRM188R61A226ME15D | Chip Multilayer Ceramic Capacitors for General Purpose, 0603, 22uF, X5R, 15%, 20%, 10V | C25 | CMP-2000-06337-3 | New From Design | Up to date | 1 | Murata | GRM188R61A226ME15D | Volume Production | Newark | 03AC2659 | 0.025 | 100
 | GRM188R61A226ME15D | Chip Multilayer Ceramic Capacitors for General Purpose, 0603, 22uF, X5R, 15%, 20%, 10V | C26 | CMP-2000-06337-3 | New From Design | Up to date | 1 | Murata | GRM188R61A226ME15D | Volume Production | Newark | 03AC2659 | 0.025 | 100
 | CGA3E2X7R1H104K080AA | Cap Ceramic 100nF 50V X7R 10% Pad SMD 0603 +125°C Automotive T/R | C27 | CMP-2000-07546-2 | New From Design | Up to date | 1 | TDK | CGA3E2X7R1H104K080AA | Volume Production | Avnet | 04X3156 | 0.026 | 0.026
 | CGA3E2X7R1H104K080AA | Cap Ceramic 100nF 50V X7R 10% Pad SMD 0603 +125°C Automotive T/R | C28 | CMP-2000-07546-2 | New From Design | Up to date | 1 | TDK | CGA3E2X7R1H104K080AA | Volume Production | Avnet | 04X3156 | 0.026 | 0.026
 | C1206C104K1RACTU | CAP CER 0.1UF 100V X7R 1206 | C29 | CMP-03020-000153-1 | New From Design | Up to date | 1 | KEMET | C1206C104K1RACTU | Volume Production | Farnell | 1414714 | 0.1202 | 1.2
 | C1206C104K1RACTU | CAP CER 0.1UF 100V X7R 1206 | C30 | CMP-03020-000153-1 | New From Design | Up to date | 1 | KEMET | C1206C104K1RACTU | Volume Production | Farnell | 1414714 | 0.1202 | 1.2
 | C0805C105K4PACTU |  | C31 | CMP-1036-04746-2 | Released | Up to date | 1 | TDK | C2012X5R1C105K/0.85 | Unknown
 | C0805C105K4PACTU |  | C32 | CMP-1036-04746-2 | Released | Up to date | 1 | TDK | C2012X5R1C105K/0.85 | Unknown
 | GRM188R60J106ME47D | Chip Multilayer Ceramic Capacitors for General Purpose, 0603, 10uF, X5R, 15%, 20%, 6.3V | C33 | CMP-2006-02792-2 | New From Design | Up to date | 1 | Murata | GRM188R60J106ME47D | Volume Production | Newark | 03AC2652 | 0.019 | 76
 | CAP 470pF 500V 1206(3216) | CAP 470pF 500V ±5% 1206 (3216 Metric) Thickness 1.3mm SMD | C34 | CMP-1037-02174-1 | Released | Up to date | 1 | Kyocera AVX | 12067A471JAT2A | Volume Production | Avnet | 01M9838 | 0.749 | 3.75
 | C1206C104K1RACTU | CAP CER 0.1UF 100V X7R 1206 | C35 | CMP-03020-000153-1 | New From Design | Up to date | 1 | KEMET | C1206C104K1RACTU | Volume Production | Farnell | 1414714 | 0.1202 | 1.2
 | C1206C104K1RACTU | CAP CER 0.1UF 100V X7R 1206 | C36 | CMP-03020-000153-1 | New From Design | Up to date | 1 | KEMET | C1206C104K1RACTU | Volume Production | Farnell | 1414714 | 0.1202 | 1.2
 | GRM188R60J106ME47D | Chip Multilayer Ceramic Capacitors for General Purpose, 0603, 10uF, X5R, 15%, 20%, 6.3V | C37 | CMP-2006-02792-2 | New From Design | Up to date | 1 | Murata | GRM188R60J106ME47D | Volume Production | Newark | 03AC2652 | 0.019 | 76
 | C0805C105K4PACTU |  | C38 | CMP-1036-04746-2 | Released | Up to date | 1 | TDK | C2012X5R1C105K/0.85 | Unknown
 | GRM188R60J106ME47D | Chip Multilayer Ceramic Capacitors for General Purpose, 0603, 10uF, X5R, 15%, 20%, 6.3V | C39 | CMP-2006-02792-2 | New From Design | Up to date | 1 | Murata | GRM188R60J106ME47D | Volume Production | Newark | 03AC2652 | 0.019 | 76
 | CAP 470pF 500V 1206(3216) | CAP 470pF 500V ±5% 1206 (3216 Metric) Thickness 1.3mm SMD | C40 | CMP-1037-02174-1 | Released | Up to date | 1 | Kyocera AVX | 12067A471JAT2A | Volume Production | Avnet | 01M9838 | 0.749 | 3.75
 | GRM188R60J106ME47D | Chip Multilayer Ceramic Capacitors for General Purpose, 0603, 10uF, X5R, 15%, 20%, 6.3V | C41 | CMP-2006-02792-2 | New From Design | Up to date | 1 | Murata | GRM188R60J106ME47D | Volume Production | Newark | 03AC2652 | 0.019 | 76
 | GRM188R60J106ME47D | Chip Multilayer Ceramic Capacitors for General Purpose, 0603, 10uF, X5R, 15%, 20%, 6.3V | C42 | CMP-2006-02792-2 | New From Design | Up to date | 1 | Murata | GRM188R60J106ME47D | Volume Production | Newark | 03AC2652 | 0.019 | 76
 | GRM188R60J106ME47D | Chip Multilayer Ceramic Capacitors for General Purpose, 0603, 10uF, X5R, 15%, 20%, 6.3V | C43 | CMP-2006-02792-2 | New From Design | Up to date | 1 | Murata | GRM188R60J106ME47D | Volume Production | Newark | 03AC2652 | 0.019 | 76
 | HSMG-C170 | Chip LED, Green, 2.2 V, -40 to 85 degC, 2-Pin SMD, Pb-Free, Tape and Reel | DS1 | CMP-2000-05062-1 | Released | Up to date | 1 | Broadcom Avago | HSMG-C170 | Volume Production | Farnell | 2361869 | 0.08324 | 332.96
 | BKP1005HS221-T | Ferrite Bead | FB1 |  | Not managed |  | 1
 | BLM15PD600SN1D | Chip Ferrite Bead, 0402, 60Ω @ 100MHz, 0.06Ω, 25%, 1.7A | FB2 | CMP-0686-00129-3 | Released | Up to date | 1 | Murata | BLM15PD600SN1D | Volume Production | Farnell | 2443231 | 0.05359 | 0.53587
 | TB67H400AHG | Integrated Circuit | IC1 |  | Not managed |  | 1
 | 22-28-4060 | CONN HEADER VERT 6POS 2.54MM | J1 | CMP-04776-000763-1 | New From Design | Up to date | 1 | Molex | 22-28-4060 | Volume Production | Avnet | 0022284060 | 0.11966 | 0.11966
 | 1604490000 | OMNIMATE Signal - series BL/SL 3.50 | J2 | CMP-1559-00905-1 | Released | Up to date | 1 | Weidmuller | 1604490000 | Volume Production | Avnet | 1604490000 | 0.86589 | 86.59
 | 691709710302 |  | J3 | CMP-1502-03335-2 | Released | Up to date | 1 | Wurth Electronics Midcom | 691709710302 | Volume Production | Digikey | 1297-1108-1-ND | 2.98 | 2.98
 | 1604490000 | OMNIMATE Signal - series BL/SL 3.50 | J4 | CMP-1559-00905-1 | Released | Up to date | 1 | Weidmuller | 1604490000 | Volume Production | Avnet | 1604490000 | 0.86589 | 86.59
 | 1604490000 | OMNIMATE Signal - series BL/SL 3.50 | J5 | CMP-1559-00905-1 | Released | Up to date | 1 | Weidmuller | 1604490000 | Volume Production | Avnet | 1604490000 | 0.86589 | 86.59
 | 1604490000 | OMNIMATE Signal - series BL/SL 3.50 | J6 | CMP-1559-00905-1 | Released | Up to date | 1 | Weidmuller | 1604490000 | Volume Production | Avnet | 1604490000 | 0.86589 | 86.59
 | IHLP2525EZER100M01 | Commercial Inductors, High Saturation Series 10uH 4.5A 71.3mΩ 20% | L1 | CMP-02424-000296-1 | New From Design | Up to date | 1 | Vishay Dale | IHLP2525EZER100M01 | Volume Production | Future Electronics | 1054017 | 0.505 | 252.5
 | 691321100002 |  | P1 | CMP-1502-01783-2 | Released | Up to date | 1 | Wurth Electronics | 691321100002 | Volume Production | Newark | 16T1532 | 0.504 | 5.04
 | RC0402JR-07100KL | RES 100K OHM 5% 1/16W 0402 | R1 | CMP-2002-07913-2 | Released | Up to date | 1 | Yageo | RC0402JR-07100KL | Volume Production | Newark | 12AC2104 | 0.002 | 20
 | RC0402JR-07100KL | RES 100K OHM 5% 1/16W 0402 | R2 | CMP-2002-07913-2 | Released | Up to date | 1 | Yageo | RC0402JR-07100KL | Volume Production | Newark | 12AC2104 | 0.002 | 20
 | RC0402JR-07100KL | RES 100K OHM 5% 1/16W 0402 | R3 | CMP-2002-07913-2 | Released | Up to date | 1 | Yageo | RC0402JR-07100KL | Volume Production | Newark | 12AC2104 | 0.002 | 20
 | RC0402JR-07100KL | RES 100K OHM 5% 1/16W 0402 | R4 | CMP-2002-07913-2 | Released | Up to date | 1 | Yageo | RC0402JR-07100KL | Volume Production | Newark | 12AC2104 | 0.002 | 20
 | RC0402JR-07100KL | RES 100K OHM 5% 1/16W 0402 | R5 | CMP-2002-07913-2 | Released | Up to date | 1 | Yageo | RC0402JR-07100KL | Volume Production | Newark | 12AC2104 | 0.002 | 20
 | RC0402JR-07100KL | RES 100K OHM 5% 1/16W 0402 | R6 | CMP-2002-07913-2 | Released | Up to date | 1 | Yageo | RC0402JR-07100KL | Volume Production | Newark | 12AC2104 | 0.002 | 20
 | RC0402JR-07100KL | RES 100K OHM 5% 1/16W 0402 | R7 | CMP-2002-07913-2 | Released | Up to date | 1 | Yageo | RC0402JR-07100KL | Volume Production | Newark | 12AC2104 | 0.002 | 20
 | RC0402JR-07100KL | RES 100K OHM 5% 1/16W 0402 | R8 | CMP-2002-07913-2 | Released | Up to date | 1 | Yageo | RC0402JR-07100KL | Volume Production | Newark | 12AC2104 | 0.002 | 20
 | RC0805FR-071KL | Chip Resistor, 1 KOhm, +/- 1%, 125 mW, -55 to 155 degC, 0805 (2012 Metric), RoHS, Tape and Reel | R9 | CMP-2100-03671-1 | Released | Up to date | 1 | Yageo | RC0805FR-071KL | Volume Production | Farnell | 2421935 | 0.00439 | 21.94
 | RC0402JR-07100KL | RES 100K OHM 5% 1/16W 0402 | R10 | CMP-2002-07913-2 | Released | Up to date | 1 | Yageo | RC0402JR-07100KL | Volume Production | Newark | 12AC2104 | 0.002 | 20
 | RC0402JR-07100KL | RES 100K OHM 5% 1/16W 0402 | R11 | CMP-2002-07913-2 | Released | Up to date | 1 | Yageo | RC0402JR-07100KL | Volume Production | Newark | 12AC2104 | 0.002 | 20
 | CRCW08053K30FKEA | RES Thick Film, 3.3kΩ, 1%, 0.125W, 100ppm/°C, 0805 | R12 | CMP-2001-03876-2 | New From Design | Up to date | 1 | Vishay | CRCW08053K30FKEA | Volume Production | Farnell | 1469911 | 0.03151 | 0.31514
 | RC0402JR-07100KL | RES 100K OHM 5% 1/16W 0402 | R13 | CMP-2002-07913-2 | Released | Up to date | 1 | Yageo | RC0402JR-07100KL | Volume Production | Newark | 12AC2104 | 0.002 | 20
 | RC0402JR-07100KL | RES 100K OHM 5% 1/16W 0402 | R14 | CMP-2002-07913-2 | Released | Up to date | 1 | Yageo | RC0402JR-07100KL | Volume Production | Newark | 12AC2104 | 0.002 | 20
 | CSRN2512FTR510 | Res Thick Film 2512 0.51Ω 1% 2W ±200ppm/°C Molded SMD Plastic T/R | R15 | CMP-26527-003119-1 | New From Design | Up to date | 1 | Stackpole Electronics | CSRN2512FTR510 | Volume Production | Digikey | 738-CSRN2512FTR510CT-ND | 0.37 | 0.37
 | ERJ-3GEYJ105V |  | R16 | CMP-2000-00706-1 | Released | Up to date | 1 | Panasonic | ERJ-3GEYJ105V | Volume Production | Future Electronics | 2028511 | 0.0078 | 39
 | CSRN2512FTR510 | Res Thick Film 2512 0.51Ω 1% 2W ±200ppm/°C Molded SMD Plastic T/R | R17 | CMP-26527-003119-1 | New From Design | Up to date | 1 | Stackpole Electronics | CSRN2512FTR510 | Volume Production | Digikey | 738-CSRN2512FTR510CT-ND | 0.37 | 0.37
 | CRCW06032K20FKEAHP | RES Thick Film, 2.2kΩ, 1%, 0.33W, 100ppm/°C, 0603 | R18 | CMP-02407-010809-1 | New From Design | Up to date | 1 | Vishay | CRCW06032K20FKEAHP | Volume Production | Newark | 12AC0228 | 0.019 | 95
 | CRCW08055K10FKEA | RES Thick Film, 5.1kΩ, 1%, 0.125W, 100ppm/°C, 0805 | R19 | CMP-2001-04024-2 | New From Design | Up to date | 1 | Vishay | CRCW08055K10FKEA | Volume Production | Farnell | 1469937 | 0.03776 | 0.37763
 | RC0805FR-0710KL | Chip Resistor, 10 KOhm, +/- 1%, 0.125 W, -55 to 155 degC, 0805 (2012 Metric), RoHS, Tape and Reel | R20 | CMP-1659-00013-4 | Released | Up to date | 1 | Yageo | RC0805FR-0710KL | Volume Production | Newark | 05M4535 | 0.1 | 0.1
 | MCR100JZHFSR062 | Thick Film Chip Resistor, 2512, 0.062Ω, 1%, 1W, 200V | R21 | CMP-08839-019952-1 | New From Design | Up to date | 1 | Rohm | MCR100JZHFSR062 | Volume Production
 | MCR100JZHFSR062 | Thick Film Chip Resistor, 2512, 0.062Ω, 1%, 1W, 200V | R22 | CMP-08839-019952-1 | New From Design | Up to date | 1 | Rohm | MCR100JZHFSR062 | Volume Production
 | CRCW1206100KFKEA |  | R23 | CMP-1014-00736-2 | Released | Up to date | 1 | Rohm | MCR18EZPF1003 | Volume Production
 | CRCW120611K0FKEA | RES Thick Film, 11kΩ, 1%, 0.25W, 100ppm/°C, 1206 | R24 | CMP-2003-04829-2 | New From Design | Up to date | 1 | Vishay | CRCW120611K0FKEA | Volume Production | Farnell | 1469978 | 0.04627 | 0.46273
 | CRCW1206120RFKEA | RES Thick Film, 120Ω, 1%, 0.25W, 100ppm/°C, 1206 | R25 | CMP-2003-04838-2 | New From Design | Up to date | 1 | Vishay | CRCW1206120RFKEA | Volume Production | Farnell | 1653057 | 0.04813 | 0.48135
 | CRCW060356R0JNEA | RES Thick Film, 56Ω, 5%, 0.1W, 200ppm/°C, 0603 | R26 | CMP-2000-03472-2 | New From Design | Up to date | 1 | Vishay Dale | CRCW060356R0JNEA | Volume Production | Farnell | 1514781 | 0.11302 | 0.11302
 | CRCW1206120RFKEA | RES Thick Film, 120Ω, 1%, 0.25W, 100ppm/°C, 1206 | R27 | CMP-2003-04838-2 | New From Design | Up to date | 1 | Vishay | CRCW1206120RFKEA | Volume Production | Farnell | 1653057 | 0.04813 | 0.48135
 | RC1206FR-071KL | Chip Resistor, 1 KOhm, +/- 1%, 0.25 W, -55 to 155 degC, 1206 (3216 Metric), RoHS, Tape and Reel | R28 | CMP-2100-03678-1 | Released | Up to date | 1 | Yageo | RC1206FR-071KL | Volume Production | Future Electronics | 1415827 | 0.0037 | 18.5
 | WSL1206R1000FEA |  | R29 | CMP-2003-04368-1 | Released | Up to date | 1 | Vishay Dale | WSL1206R1000FEA | Volume Production | Farnell | 1107359 | 0.72468 | 7.25
 | ERJ8ENF33R0V |  | R30 | CMP-2003-00837-1 | Released | Up to date | 1 | Panasonic | ERJ-8ENF33R0V | Not Recommended for New Design | Farnell | 2307634 | 0.07007 | 0.70075
 | ERJ-8RQFR22V |  | R31 | CMP-2003-00694-1 | Released | Up to date | 1 | Panasonic | ERJ-8RQFR22V | Volume Production | Newark | 27AC5482 | 0.034 | 170
 | RC1206FR-071KL | Chip Resistor, 1 KOhm, +/- 1%, 0.25 W, -55 to 155 degC, 1206 (3216 Metric), RoHS, Tape and Reel | R32 | CMP-2100-03678-1 | Released | Up to date | 1 | Yageo | RC1206FR-071KL | Volume Production | Future Electronics | 1415827 | 0.0037 | 18.5
 | WSL1206R1000FEA |  | R33 | CMP-2003-04368-1 | Released | Up to date | 1 | Vishay Dale | WSL1206R1000FEA | Volume Production | Farnell | 1107359 | 0.72468 | 7.25
 | ERJ8ENF33R0V |  | R34 | CMP-2003-00837-1 | Released | Up to date | 1 | Panasonic | ERJ-8ENF33R0V | Not Recommended for New Design | Farnell | 2307634 | 0.07007 | 0.70075
 | 3-1825910-1 | SWITCH TACTILE SPST-NO 0.05A 24V | SW1 | CMP-03407-000001-1 | New From Design | Up to date | 1 | TE Connectivity | 3-1825910-1 | Volume Production | Farnell | 2531294 | 0.32843 | 0.32843
 | 5003 | Test Point, Orange, Height 4.6 mm, Tail Length 3 mm, 1-Pin THD, RoHS | TP1 |  | Unknown server |  | 1
 | 5003 | Test Point, Orange, Height 4.6 mm, Tail Length 3 mm, 1-Pin THD, RoHS | TP2 |  | Unknown server |  | 1
 | 5003 | Test Point, Orange, Height 4.6 mm, Tail Length 3 mm, 1-Pin THD, RoHS | TP3 |  | Unknown server |  | 1
 | TMS320F28069PFPS | Piccolo Microcontroller, High-Efficiency 32-Bit CPU, 100 KB, 90 MHz, FPU, VCU, 17 Ch PWM, 40 GPIO, 3.3 V, -40 to 125 degC, 80-Pin HTQFP (PFP), Green (RoHS & no Sb/Br) | U1 | CMP-0546-00011-3 | Released | Up to date | 1 | Texas Instruments | TMS320F28069PFPS | Volume Production | Digikey | 296-41899-ND | 18.05 | 18.05
 | TPS54302DDCR | IC REG BUCK ADJ 3A TSOT23-6 | U2 | CMP-04918-000032-1 | New From Design | Up to date | 1 | Texas Instruments | TPS54302DDCR | Volume Production | Digikey | 296-46237-1-ND | 1.06 | 1.06
 | TLV76133DCYR | TLV76133DCYR 1A 16V high-PSRR linear voltage regulator 4-SOT-223 -40 to 125 | U3 | CMP-00370-135533165-1 | New From Design | Up to date | 1 | Texas Instruments | TLV76133DCYR | Unknown | Digikey | 296-TLV76133DCYRCT-ND | 0.41 | 0.41
 | LT1763CS8-5#TRPBF | 500 mA, Low Noise, LDO Micropower Regulator, 1.8 to 20 V Vin, 5 V Vout, 8-pin SOIC (S8-8), -40 to 125 degC, Pb-Free, Tape and Reel | U4 | CMP-0476-01689-1 | Released | Up to date | 1 | Analog Devices / Linear Technology | LT1763CS8-5#TRPBF | Volume Production | Farnell | 4027245 | 7.83 | 7.83
 | TXS0104EPWR | Integrated Circuit | U5 |  | Not managed |  | 1
 | AM26LS32ACDR | Quadruple Differential Line Receiver, 0 TX / 4 RX, 0 to 70 degC, 16-Pin SOIC (D), Green (RoHS & no Sb/Br) | U6 | CMP-0310-00258-2 | Released | Up to date | 1 | Texas Instruments | AM26LS32ACDR | Volume Production | Digikey | 296-1011-1-ND | 0.55 | 0.55
 | INA241B1IDDFR | -5-V to 110-V, bidirectional, high-precision current sense amplifier with enhanced PWM rejection 8-SOT-23-THIN -40 to... | U7 |  | Not managed |  | 1
 | INA241B1IDDFR | -5-V to 110-V, bidirectional, high-precision current sense amplifier with enhanced PWM rejection 8-SOT-23-THIN -40 to... | U8 |  | Not managed |  | 1
 | REF5045AID | Low Noise, Very Low Drift, Precision Voltage Reference, -40 to 125 degC, 8-pin SOIC (D), Green (RoHS & no Sb/Br) | U9 | CMP-0367-00016-2 | Released | Up to date | 1 | Texas Instruments | REF5045AID | Volume Production | Digikey | 296-22209-5-ND | 4 | 4
 | OPA2350UA/2K5 | High-Speed, Single-Supply, Rail-to-Rail Operational Amplifier MicroAmplifier(TM) Series, 2.7 to 5.5 V, -40 to 85 degC, 8-pin SOIC (D8), Green (RoHS & no Sb/Br) | U10 | CMP-0272-00732-3 | Released | Up to date | 1 | Texas Instruments | OPA2350UA/2K5 | Volume Production | Digikey | 296-26258-1-ND | 4.54 | 4.54
 | OPA2836IDR | Dual, Very Low Power, Rail to Rail Out, Negative Rail In, VFB Operational Amplifier, 2.5 to 5.5 V, -40 to 85 degC, 8-pin SOIC (D8), Green (RoHS & no Sb/Br) | U11 | CMP-0018-00293-2 | Released | Up to date | 1 | Texas Instruments | OPA2836IDR | Volume Production | Digikey | 296-OPA2836IDRCT-ND | 3.82 | 3.82
 | ADS7853IPW | ADC, Proprietary Method, 14-Bit, 1 Func, 2 Channel, Serial Access, PDSO16 | U12 |  | Not managed |  | 1
 | ECS-200-20-28AX-TR | SMD Quartz Crystal | Y1 |  | Not managed |  | 1

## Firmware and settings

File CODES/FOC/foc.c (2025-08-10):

#include "F2806x_Device.h"
#include "F2806x_Examples.h"
#include "IQmathLib.h"

// Define constants
#define M_PI 3.14159265358979323846
#define POLE_PAIRS 50           // NEMA 17: 200 steps/rev = 50 pole pairs
#define RS 2.0                  // Stator resistance (ohms)
#define LS 0.002                // Stator inductance (H)
#define VDC 12.0                // DC bus voltage (V)
#define PWM_PERIOD 4500         // 10kHz PWM (90MHz / (2 * 4500))
#define CURRENT_MAX 2.0         // Max current (A)
#define SPEED_MAX 1000.0        // Max speed (RPM)
#define ADC_OFFSET 2048         // 12-bit ADC midpoint
#define ADC_GAIN 0.1            // Current sensor gain (A/V)

// PI controller gains
#define KP_D 0.5                // D-axis current proportional gain
#define KI_D 0.01               // D-axis current integral gain
#define KP_Q 0.5                // Q-axis current proportional gain
#define KI_Q 0.01               // Q-axis current integral gain
#define KP_SPEED 0.1            // Speed proportional gain
#define KI_SPEED 0.001          // Speed integral gain

// Global variables
_iq Id_ref = _IQ(0.0);          // D-axis current reference
_iq Iq_ref = _IQ(0.0);          // Q-axis current reference
_iq speed_ref = _IQ(100.0);     // Speed reference (RPM)
_iq theta_e = _IQ(0.0);         // Electrical angle
_iq Ia, Ib;                     // Phase currents
_iq Ialpha, Ibeta;              // Clarke transform outputs
_iq Id, Iq;                     // Park transform outputs
_iq Vd, Vq;                     // Voltage outputs
_iq Valpha, Vbeta;              // Inverse Park transform outputs
_iq speed = _IQ(0.0);           // Measured speed
Uint32 encoder_pos;             // Encoder position
static Uint32 last_pos = 0;     // Previous encoder position
Uint16 led_state = 0;           // LED state
Uint32 loop_count = 0;          // Loop counter for LED

// Function prototypes
void init_system(void);
void init_adc(void);
void init_eqep(void);
void init_pwm(void);
void read_currents(void);
void read_encoder(void);
void clarke_transform(void);
void park_transform(void);
void pi_current_control(void);
void pi_speed_control(void);
void inv_park_transform(void);
void svgen_pwm(void);
void toggle_led(void);
_iq _IQsgn(_iq value);

// Interrupt service routines
__interrupt void adc_isr(void);
__interrupt void timer0_isr(void);

// Main function
void main(void) {
    init_system();
    init_adc();
    init_eqep();
    init_pwm();

    // Enable interrupts
    EINT;
    ERTM;

    while(1) {
        // Blink LED every 500ms
        if (loop_count++ >= 450000) { // 90MHz * 500ms
            toggle_led();
            loop_count = 0;
        }
    }
}

// System initialization
void init_system(void) {
    InitSysCtrl(); // Initialize system clock (90 MHz)
    DINT;

    InitPieCtrl();
    IER = 0x0000;
    IFR = 0x0000;

    InitPieVectTable();
    EALLOW;
    PieVectTable.ADCINT1 = &adc_isr;
    PieVectTable.TINT0 = &timer0_isr;
    EDIS;

    // Configure LED (GPIO34)
    EALLOW;
    GpioCtrlRegs.GPBMUX1.bit.GPIO34 = 0;
    GpioCtrlRegs.GPBDIR.bit.GPIO34 = 1;
    GpioDataRegs.GPBCLEAR.bit.GPIO34 = 1;
    EDIS;
}

// ADC initialization
void init_adc(void) {
    InitAdc();
    EALLOW;
    AdcRegs.ADCCTL1.bit.INTPULSEPOS = 1;
    AdcRegs.ADCCTL1.bit.ADCBGPWD = 1;
    AdcRegs.ADCCTL1.bit.ADCPWDN = 1;

    AdcRegs.ADCSOC0CTL.bit.CHSEL = 0; // ADCINA0 (Ia)
    AdcRegs.ADCSOC1CTL.bit.CHSEL = 1; // ADCINA1 (Ib)
    AdcRegs.ADCSOC0CTL.bit.ACQPS = 6;
    AdcRegs.ADCSOC1CTL.bit.ACQPS = 6;
    AdcRegs.ADCSOC0CTL.bit.TRIGSEL = 5; // ePWM1 SOCA
    AdcRegs.ADCSOC1CTL.bit.TRIGSEL = 5;

    AdcRegs.ADCINTSOCSEL1.bit.SOC1 = 1; // SOC1 triggers ADCINT1
    AdcRegs.ADCINTFLGCLR.bit.ADCINT1 = 1;
    AdcRegs.INTSEL1N2.bit.INT1E = 1; // Enable ADCINT1
    PieCtrlRegs.PIEIER1.bit.INTx1 = 1;
    EDIS;

    AdcRegs.ADCSOCFRC1.all = 0x0003; // Force SOC0 and SOC1
}

// eQEP initialization
void init_eqep(void) {
    InitEQep1Gpio();
    EALLOW;
    EQep1Regs.QEPCTL.bit.QPEN = 1;
    EQep1Regs.QDECCTL.bit.QSRC = 0;
    EQep1Regs.QPOSMAX = 200 * POLE_PAIRS - 1;
    EQep1Regs.QPOSINIT = 0;
    EQep1Regs.QEPCTL.bit.PCRM = 0;
    EQep1Regs.QEINT.bit.PCE = 1; // Position counter error interrupt
    EQep1Regs.QCLR.bit.PCE = 1;
    EDIS;
}

// PWM initialization
void init_pwm(void) {
    InitEPwm1Gpio();
    InitEPwm2Gpio();
    EALLOW;

    EPwm1Regs.TBCTL.bit.CTRMODE = 3;
    EPwm1Regs.TBPRD = PWM_PERIOD;
    EPwm1Regs.CMPA.half.CMPA = 0;
    EPwm1Regs.AQCTLA.bit.CAU = 2;
    EPwm1Regs.AQCTLA.bit.CAD = 1;
    EPwm1Regs.TBCTL.bit.PHSEN = 0;

    EPwm2Regs.TBCTL.bit.CTRMODE = 3;
    EPwm2Regs.TBPRD = PWM_PERIOD;
    EPwm2Regs.CMPA.half.CMPA = 0;
    EPwm2Regs.AQCTLA.bit.CAU = 2;
    EPwm2Regs.AQCTLA.bit.CAD = 1;
    EPwm2Regs.TBCTL.bit.PHSEN = 0;

    EPwm1Regs.ETSEL.bit.SOCAEN = 1;
    EPwm1Regs.ETSEL.bit.SOCASEL = 1;
    EPwm1Regs.ETPS.bit.SOCAPRD = 1;
    EDIS;

    InitCpuTimers();
    ConfigCpuTimer(&CpuTimer0, 90, 100); // 10kHz
    CpuTimer0Regs.TCR.bit.TSS = 0;
}

// Read phase currents
void read_currents(void) {
    Ia = _IQmpy(_IQ(AdcResult.ADCRESULT0 - ADC_OFFSET), _IQ(ADC_GAIN));
    Ib = _IQmpy(_IQ(AdcResult.ADCRESULT1 - ADC_OFFSET), _IQ(ADC_GAIN));
}

// Read encoder and compute speed
void read_encoder(void) {
    _iq delta_pos;

    encoder_pos = EQep1Regs.QPOSCNT;
    theta_e = _IQmpy(_IQ(encoder_pos), _IQ(2.0 * M_PI / (200.0 * POLE_PAIRS)));
    delta_pos = _IQ(encoder_pos - last_pos);
    speed = _IQmpy(delta_pos, _IQ(60.0 / (0.0001 * 200.0 * POLE_PAIRS)));
    last_pos = encoder_pos;
}

// Clarke transform
void clarke_transform(void) {
    Ialpha = Ia;
    Ibeta = _IQmpy(_IQ(0.57735026919), Ia) + _IQmpy(_IQ(1.15470053838), Ib);
}

// Park transform
void park_transform(void) {
    _iq cos_theta = _IQcos(theta_e);
    _iq sin_theta = _IQsin(theta_e);
    Id = _IQmpy(Ialpha, cos_theta) + _IQmpy(Ibeta, sin_theta);
    Iq = _IQmpy(Ibeta, cos_theta) - _IQmpy(Ialpha, sin_theta);
}

// PI control for currents
void pi_current_control(void) {
    static _iq Id_error_int = _IQ(0.0), Iq_error_int = _IQ(0.0);
    _iq Id_error, Iq_error, Vmax;

    Id_error = Id_ref - Id;
    Iq_error = Iq_ref - Iq;
    Vmax = _IQ(VDC * 0.5);

    Id_error_int += _IQmpy(KI_D, Id_error);
    if (_IQabs(Id_error_int) > Vmax) Id_error_int = _IQmpy(Vmax, _IQsgn(Id_error_int));
    Iq_error_int += _IQmpy(KI_Q, Iq_error);
    if (_IQabs(Iq_error_int) > Vmax) Iq_error_int = _IQmpy(Vmax, _IQsgn(Iq_error_int));

    Vd = _IQmpy(KP_D, Id_error) + Id_error_int;
    Vq = _IQmpy(KP_Q, Iq_error) + Iq_error_int;

    if (_IQabs(Vd) > Vmax) Vd = _IQmpy(Vmax, _IQsgn(Vd));
    if (_IQabs(Vq) > Vmax) Vq = _IQmpy(Vmax, _IQsgn(Vq));
}

// PI control for speed
void pi_speed_control(void) {
    static _iq speed_error_int = _IQ(0.0);
    _iq speed_error;

    speed_error = speed_ref - speed;
    speed_error_int += _IQmpy(KI_SPEED, speed_error);
    if (_IQabs(speed_error_int) > _IQ(CURRENT_MAX)) speed_error_int = _IQmpy(_IQ(CURRENT_MAX), _IQsgn(speed_error_int));

    Iq_ref = _IQmpy(KP_SPEED, speed_error) + speed_error_int;
    Id_ref = _IQ(0.0);

    if (_IQabs(Iq_ref) > _IQ(CURRENT_MAX)) Iq_ref = _IQmpy(_IQ(CURRENT_MAX), _IQsgn(Iq_ref));
}

// Inverse Park transform
void inv_park_transform(void) {
    _iq cos_theta = _IQcos(theta_e);
    _iq sin_theta = _IQsin(theta_e);
    Valpha = _IQmpy(Vd, cos_theta) - _IQmpy(Vq, sin_theta);
    Vbeta = _IQmpy(Vd, sin_theta) + _IQmpy(Vq, cos_theta);
}

// Space vector PWM
void svgen_pwm(void) {
    _iq Va, Vb;
    Uint16 cmpa, cmpb;
    float temp;

    Va = Valpha;
    Vb = _IQmpy(_IQ(-0.5), Valpha) + _IQmpy(_IQ(0.86602540378), Vbeta);

    temp = _IQtoF(_IQmpy(_IQ(Va / VDC), _IQ(PWM_PERIOD / 2)) + _IQ(PWM_PERIOD / 2));
    cmpa = (temp >= 0 && temp <= PWM_PERIOD) ? (Uint16)temp : (temp > PWM_PERIOD ? PWM_PERIOD : 0);

    temp = _IQtoF(_IQmpy(_IQ(Vb / VDC), _IQ(PWM_PERIOD / 2)) + _IQ(PWM_PERIOD / 2));
    cmpb = (temp >= 0 && temp <= PWM_PERIOD) ? (Uint16)temp : (temp > PWM_PERIOD ? PWM_PERIOD : 0);

    EPwm1Regs.CMPA.half.CMPA = cmpa;
    EPwm2Regs.CMPA.half.CMPA = cmpb;
}

// Toggle LED
void toggle_led(void) {
    led_state = !led_state;
    GpioDataRegs.GPBSET.bit.GPIO34 = led_state;
    GpioDataRegs.GPBCLEAR.bit.GPIO34 = !led_state;
}

// Custom IQ sign function
_iq _IQsgn(_iq value) {
    if (_IQtoF(value) > 0) return _IQ(1.0);
    if (_IQtoF(value) < 0) return _IQ(-1.0);
    return _IQ(0.0);
}

// ADC ISR
__interrupt void adc_isr(void) {
    read_currents();
    clarke_transform();
    park_transform();
    pi_current_control();
    inv_park_transform();
    svgen_pwm();

    AdcRegs.ADCINTFLGCLR.bit.ADCINT1 = 1;
    PieCtrlRegs.PIEACK.all = PIEACK_GROUP1;
}

// Timer ISR
__interrupt void timer0_isr(void) {
    read_encoder();
    pi_speed_control();

    CpuTimer0Regs.TCR.bit.TIF = 1;
    PieCtrlRegs.PIEACK.all = PIEACK_GROUP1;
}

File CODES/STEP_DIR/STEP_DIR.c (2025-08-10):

#include "F2806x_Device.h"
#include "F2806x_Examples.h"
#include "IQmathLib.h"

// Define constants
#define POLE_PAIRS 50           // NEMA 17: 200 steps/rev = 50 pole pairs
#define ENCODER_PPR 200         // Encoder pulses per revolution (adjust if 1000 PPR)
#define STEPS_PER_REV 200       // NEMA 17 steps per revolution (1x stepping)
#define DEFAULT_RPM 100.0       // Default speed (RPM)
#define SYSCLK 90e6             // System clock (Hz)
#define MAX_INPUT_LEN 32        // Max Serial input length

// Global variables
_iq speed_ref = _IQ(DEFAULT_RPM); // Speed reference (RPM)
_iq speed = _IQ(0.0);           // Measured speed (RPM)
int32 target_pos = 0;           // Target position (steps)
int32 current_pos = 0;          // Current position (steps)
Uint16 dir_state = 0;           // Direction (0: forward, 1: reverse)
Uint32 encoder_pos;             // Encoder position
static Uint32 last_pos = 0;     // Previous encoder position
Uint16 led_state = 0;           // LED state
Uint32 loop_count = 0;          // Loop counter for LED
char rx_buffer[MAX_INPUT_LEN];  // Serial input buffer
Uint16 rx_index = 0;            // Buffer index
volatile Uint16 rx_ready = 0;   // Flag for complete input

// Function prototypes
void init_system(void);
void init_eqep(void);
void init_pwm(void);
void init_scia(void);
void read_encoder(void);
void update_stepper(void);
void toggle_led(void);
void scia_msg(char *msg);
void parse_input(void);

// Interrupt service routines
__interrupt void timer0_isr(void);
__interrupt void scia_rx_isr(void);

// Main function
void main(void) {
    init_system();
    init_eqep();
    init_pwm();
    init_scia();

    // Enable interrupts
    EINT;
    ERTM;

    // Send initial prompt
    scia_msg("Enter position (steps) and direction (0=forward, 1=reverse), e.g., 'P1000 D0'\r\n");

    while(1) {
        // Blink LED every 500ms
        if (loop_count++ >= 450000) { // 90MHz * 500ms
            toggle_led();
            loop_count = 0;
        }
        // Process Serial input
        if (rx_ready) {
            parse_input();
            rx_ready = 0;
        }
    }
}

// System initialization
void init_system(void) {
    InitSysCtrl(); // Initialize system clock (90 MHz)
    DINT;

    // Disable watchdog
    EALLOW;
    SysCtrlRegs.WDCR = 0x0068;
    EDIS;

    InitPieCtrl();
    IER = 0x0000;
    IFR = 0x0000;

    InitPieVectTable();
    EALLOW;
    PieVectTable.TINT0 = &timer0_isr;
    PieVectTable.SCIRXINTA = &scia_rx_isr;
    EDIS;

    // Configure LED (GPIO34)
    EALLOW;
    GpioCtrlRegs.GPBMUX1.bit.GPIO34 = 0;
    GpioCtrlRegs.GPBDIR.bit.GPIO34 = 1;
    GpioDataRegs.GPBCLEAR.bit.GPIO34 = 1;

    // Configure DIR pin (GPIO7)
    GpioCtrlRegs.GPAMUX1.bit.GPIO7 = 0;
    GpioCtrlRegs.GPADIR.bit.GPIO7 = 1;
    GpioDataRegs.GPACLEAR.bit.GPIO7 = 1; // Forward
    EDIS;
}

// eQEP initialization
void init_eqep(void) {
    InitEQep1Gpio();
    EALLOW;
    EQep1Regs.QEPCTL.bit.QPEN = 1; // Enable eQEP
    EQep1Regs.QDECCTL.bit.QSRC = 0; // Quadrature count mode
    EQep1Regs.QPOSMAX = ENCODER_PPR * 4 * POLE_PAIRS - 1; // 39999 for 200 PPR
    EQep1Regs.QPOSINIT = 0;
    EQep1Regs.QEPCTL.bit.PCRM = 0; // Position counter reset on index
    EQep1Regs.QEINT.bit.PCE = 0; // Disable PCE interrupt
    EQep1Regs.QCLR.bit.PCE = 1;
    EDIS;
}

// PWM initialization for STEP pulses
void init_pwm(void) {
    EALLOW;
    InitEPwm4Gpio(); // GPIO6 (ePWM4A) for STEP
    EPwm4Regs.TBCTL.bit.CTRMODE = 0; // Up-count mode
    EPwm4Regs.TBPRD = 13499; // 3333.33 Hz for 100 RPM (90 MHz / (200 * 100 / 60))
    EPwm4Regs.CMPA.half.CMPA = 6750; // 50% duty cycle
    EPwm4Regs.AQCTLA.bit.ZRO = 2; // Set high at TBCTR = 0
    EPwm4Regs.AQCTLA.bit.CAU = 1; // Clear low at CMPA
    EPwm4Regs.TBCTL.bit.PHSEN = 0; // Disable phase sync
    EDIS;

    InitCpuTimers();
    ConfigCpuTimer(&CpuTimer0, 90, 100); // 10 kHz ISR
    CpuTimer0Regs.TCR.bit.TSS = 0; // Start timer
}

// SCI-A initialization for Serial
void init_scia(void) {
    EALLOW;
    SysCtrlRegs.PCLKCR0.bit.SCIAENCLK = 1;
    GpioCtrlRegs.GPAMUX2.bit.GPIO28 = 1; // TX
    GpioCtrlRegs.GPAMUX2.bit.GPIO29 = 1; // RX
    GpioCtrlRegs.GPAPUD.bit.GPIO28 = 0;
    GpioCtrlRegs.GPAPUD.bit.GPIO29 = 0;
    SciaRegs.SCICCR.all = 0x0007; // 8-bit, no parity, 1 stop bit
    SciaRegs.SCICTL1.all = 0x0003; // Enable TX, RX
    SciaRegs.SCIHBAUD = 0x0000;
    SciaRegs.SCILBAUD = 0x0068; // 9600 baud at 90 MHz
    SciaRegs.SCICTL2.bit.RXBKINTENA = 1; // Enable RX interrupt
    SciaRegs.SCICTL1.bit.SWRESET = 1;
    PieCtrlRegs.PIEIER9.bit.INTx1 = 1; // Enable SCIRXINTA
    IER |= M_INT9; // Enable PIE group 9
    EDIS;
}

// Read encoder and compute speed
void read_encoder(void) {
    _iq delta_pos;
    encoder_pos = EQep1Regs.QPOSCNT;
    delta_pos = _IQ(encoder_pos - last_pos);
    speed = _IQmpy(delta_pos, _IQ(60.0 / (0.0001 * ENCODER_PPR * 4.0 * POLE_PAIRS)));
    current_pos = (int32)(encoder_pos / (ENCODER_PPR * 4.0 / STEPS_PER_REV)); // Steps
    last_pos = encoder_pos;
}

// Update stepper speed and direction
void update_stepper(void) {
    // Stop if target position reached
    if (current_pos == target_pos) {
        EPwm4Regs.TBCTL.bit.CTRMODE = 3; // Disable PWM
        return;
    }

    // Set direction
    GpioDataRegs.GPASET.bit.GPIO7 = dir_state;
    GpioDataRegs.GPACLEAR.bit.GPIO7 = !dir_state;

    // Enable PWM if stopped
    if (EPwm4Regs.TBCTL.bit.CTRMODE == 3) {
        EALLOW;
        EPwm4Regs.TBCTL.bit.CTRMODE = 0; // Up-count mode
        EDIS;
    }

    // Calculate STEP frequency: steps/sec = (steps/rev * RPM) / 60
    float rpm = _IQtoF(speed_ref);
    Uint32 freq = (Uint32)(STEPS_PER_REV * rpm / 60.0);
    Uint16 tbprd = (freq > 0) ? (Uint16)(SYSCLK / freq - 1) : 13499;
    EALLOW;
    EPwm4Regs.TBPRD = tbprd;
    EPwm4Regs.CMPA.half.CMPA = tbprd / 2; // 50% duty
    EDIS;
}

// Toggle LED
void toggle_led(void) {
    led_state = !led_state;
    GpioDataRegs.GPBSET.bit.GPIO34 = led_state;
    GpioDataRegs.GPBCLEAR.bit.GPIO34 = !led_state;
}

// Send Serial message
void scia_msg(char *msg) {
    while (*msg != '\0') {
        while (SciaRegs.SCIFFTX.bit.TXFFST == 16);
        SciaRegs.SCITXBUF = *msg++;
    }
}

// Parse Serial input (e.g., "P1000 D0")
void parse_input(void) {
    char *token;
    char buffer[MAX_INPUT_LEN];
    strcpy(buffer, rx_buffer);

    // Parse position
    token = strtok(buffer, " ");
    if (token != NULL && token[0] == 'P') {
        target_pos = atol(token + 1);
        scia_msg("Target Position: ");
        scia_msg(token + 1);
        scia_msg(" steps\r\n");
    }

    // Parse direction
    token = strtok(NULL, " ");
    if (token != NULL && token[0] == 'D') {
        dir_state = atoi(token + 1);
        scia_msg("Direction: ");
        scia_msg(dir_state ? "Reverse" : "Forward");
        scia_msg("\r\n");
    }

    // Clear buffer
    rx_index = 0;
    rx_buffer[0] = '\0';
}
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
